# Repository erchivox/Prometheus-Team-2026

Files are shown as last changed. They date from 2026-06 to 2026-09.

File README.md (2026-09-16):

<div align="center">
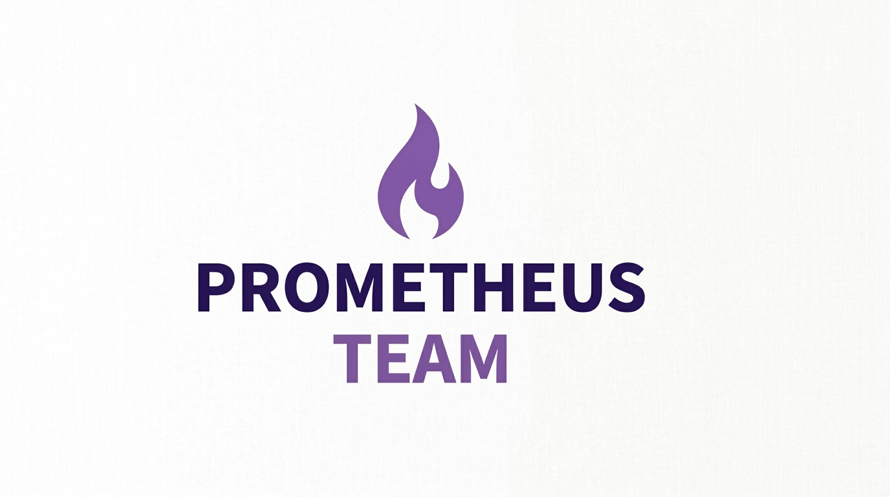
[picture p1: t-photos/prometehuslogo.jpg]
Prometheus Team Vehículo Autónomo
  

# 🚘Prometheus Team - Temporada 2026
</div>
¡Bienvenidos al repositorio oficial de nuestro equipo para la World Robot Olympiad (WRO) - Categoría: Futuros Ingenieros! Este espacio no solo almacena líneas de código, algoritmos de visión artificial y diseños en 3D; aquí se guarda la evolución, la pasión y la ingeniería de un equipo que no se rinde ante  los desafíos. Somos un equipo venezolano representando con orgullo a la **Universidad Politécnica Territorial José Félix Ribas (UPTJFR)**. Nuestro compromiso es la innovación y el aprendizaje continuo en el campo de la robótica autónoma. Queremos continuar lo que empezamos el año pasado y superar nuestros limites esta temporada.

---

## 📑 Índice

<table>
<tr><td valign="top" width="50%">

- [1. Fotos del Equipo](#1-fotos-del-equipo)
- [2. La Hazaña de 2025: Subcampeones Nacionales](#2-la-hazaña-de-2025-subcampeones-nacionales)
- [3. 2026: Con la Mira en el Primer Lugar](#3-2026-con-la-mira-en-el-primer-lugar)
- [4. Fotos del Vehículo](#4-fotos-del-vehículo)
- [5. Componentes de Control, Detección e Interfaz](#5-componentes-de-control-detección-e-interfaz)
- [6. Componentes de Alimentación y Actuación](#6-componentes-de-alimentación-y-actuación)
- [7. Esquemas de Alimentación y Cableado](#7-esquemas-de-alimentación-y-cableado)
  - [7.1. Versión 4 (Actual)](#71-versión-4-actual)
  - [7.2. Arquitectura de Energía, Control y Gestión de Potencia](#72-arquitectura-de-energía-control-y-gestión-de-potencia)
- [8. Esquemas de Sensores y Adquisición de Datos](#8-esquemas-de-sensores-y-adquisición-de-datos)
  - [8.1. Versión 4 (Actual)](#81-versión-4-actual)
  - [8.2. Optimización del Sistema de Sensores y Hardware](#82-optimización-del-sistema-de-sensores-y-hardware)
    - [8.2.1. Subsistema de Navegación Cinemática (Bus I2C 1)](#821-subsistema-de-navegación-cinemática-bus-i2c-1)
    - [8.2.2. Subsistema de Lectura de Superficie (Bus I2C 2)](#822-subsistema-de-lectura-de-superficie-bus-i2c-2)
    - [8.2.3. Subsistema de Proximidad Redundante e Interfaz](#823-subsistema-de-proximidad-redundante-e-interfaz)
  - [8.3. Resumen de Cambios y Evolución de Hardware](#83-resumen-de-cambios-y-evolución-de-hardware)
- [9. Gestión Energética y Autonomía del Sistema](#9-gestión-energética-y-autonomía-del-sistema)
  - [9.1. Cálculo del Consumo Energético Total](#91-cálculo-del-consumo-energético-total)
  - [9.2. Estimación de la Autonomía](#92-estimación-de-la-autonomía)
    - [9.2.1. Fórmula General](#921-fórmula-general)
    - [9.2.2. Aplicación al Caso de Estudio](#922-aplicación-al-caso-de-estudio)
  - [9.3. Justificación de la Fuente de Alimentación](#93-justificación-de-la-fuente-de-alimentación)
    - [9.3.1. Elección del Sistema: ¿Por qué LiPo?](#931-elección-del-sistema-por-qué-lipo)
    - [9.3.2. Análisis Comparativo de Tecnologías](#932-análisis-comparativo-de-tecnologías)
    - [9.3.3. Justificación Técnica frente a Alternativas](#933-justificación-técnica-frente-a-alternativas)

</td><td valign="top" width="50%">

- [10. Diseño Estructural, Transmisión y Manufactura Aditiva](#10-diseño-estructural-transmisión-y-manufactura-aditiva)
  - [10.1. Versión 2 (Actual)](#101-versión-2-actual)
  - [10.2. Filosofía de Rediseño y Prototipado Conceptual](#102-filosofía-de-rediseño-y-prototipado-conceptual)
    - [10.2.1. Prototipos Conceptuales Tempranos](#1021-prototipos-conceptuales-tempranos)
  - [10.3. Transición a CAD Profesional y Arquitectura Monochasis](#103-transición-a-cad-profesional-y-arquitectura-monochasis)
    - [10.3.1. Desglose Técnico del Tren Motriz](#1031-desglose-técnico-del-tren-motriz)
  - [10.4. Validación de Tolerancias y Ensamble Virtual](#104-validación-de-tolerancias-y-ensamble-virtual)
    - [10.4.1. Modelado de Componentes Clave y Sistemas de Anclaje](#1041-modelado-de-componentes-clave-y-sistemas-de-anclaje)
    - [10.4.2. Acoplamiento de Tracción: Adaptador para Ruedas Lego](#1042-acoplamiento-de-tracción-adaptador-para-ruedas-lego)
    - [10.4.3. Ensamble Virtual y Mitigación de Fallos](#1043-ensamble-virtual-y-mitigación-de-fallos)
  - [10.5. Segundo Piso, Separadores y Sistema de Visión Shark Fin](#105-segundo-piso-separadores-y-sistema-de-visión-shark-fin)
    - [10.5.1. Separadores Estructurales e Insertos Roscados](#1051-separadores-estructurales-e-insertos-roscados)
    - [10.5.2. Sistema de Sujeción del Teléfono (Mordaza Ajustable)](#1052-sistema-de-sujeción-del-teléfono-mordaza-ajustable)
  - [10.6. Integración Total: Ensamble Maestro CAD](#106-integración-total-ensamble-maestro-cad)
  - [10.7. Ingeniería de Manufactura Aditiva](#107-ingeniería-de-manufactura-aditiva)
    - [10.7.1. Optimizaciones de Impresión](#1071-optimizaciones-de-impresión)
  - [10.8. Dimensiones Finales y Resumen de Logros Estructurales](#108-dimensiones-finales-y-resumen-de-logros-estructurales)
- [11. Continuidad en el Desarrollo de Software y Control](#11-continuidad-en-el-desarrollo-de-software-y-control)
  - [11.1. Integración del BNO055](#111-integración-del-bno055)
  - [11.2. Resumen Ejecutivo de la Lógica de Control](#112-resumen-ejecutivo-de-la-lógica-de-control)
    - [11.2.1. Modo Vuelta Libre (Navegación de Pista Vacía)](#1121-modo-vuelta-libre-navegación-de-pista-vacía)
- [12. Prueba de Vueltas a la Pista](#12-prueba-de-vueltas-a-la-pista)
- [13. Archivo Histórico: Temporada 2025](#13-archivo-histórico-temporada-2025)

</td></tr>
</table>

---

## 1. Equipo Prometheus 
Prometheus Team está conformados por estudiantes universitarios de la **Universidad Politécnica Territorial "José Félix Ribas"**, destancandonos por nuestra anterior participación en la WRO 2025 y nuestro sistema de detección innovador:

### 1.1. 👤 Samuel Pérez 
**Diseñador de Entornos 3D, Desarrollador Móvil y Modelado CAD**
<div align="center">
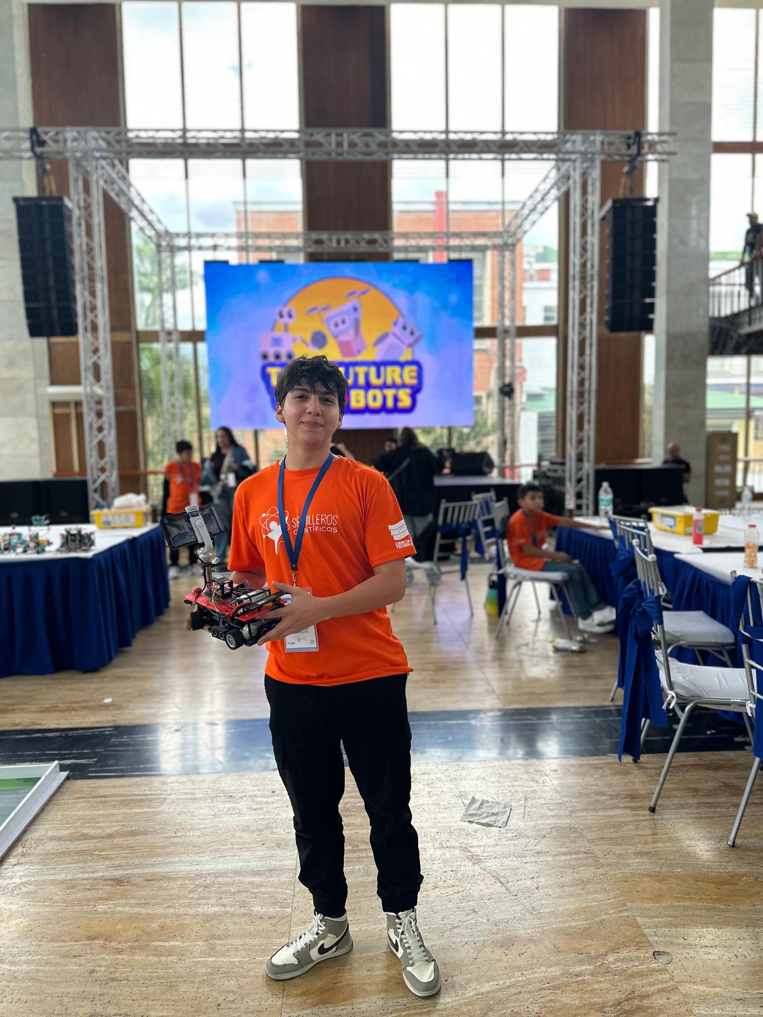
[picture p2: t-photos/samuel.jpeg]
Samuel Pérez
  
</div>

* **Trayectoria Académica:** Estudiante de Ingeniería Electrónica – **Universidad Politécnica Territorial José Félix Ribas (UPTJFR)**.
* **Competencias y Funciones Técnicas:**
  * **Diseño Estructural y Modelado 3D:** Creación paramétrica y desarrollo de componentes mecánicos optimizados para alta resistencia.
  * **Desarrollo de Software Móvil:** Creación de aplicaciones interactivas en **Android Studio** orientadas a la gestión y monitoreo de sistemas.
  * **Gestión de Proyectos:** Caracterizado por su alto nivel de responsabilidad, perseverancia y atención al detalle en entregables técnicos.
  * **Logros Destacados:** Finalista en la fase nacional de la **WRO Venezuela (Temporada 2025)** por su integración entre hardware y software.
---
### 1.2. 👤 Trino Carrizales 
**Especialista en Programación Embebida, Algoritmos y Control**
<div align="center">
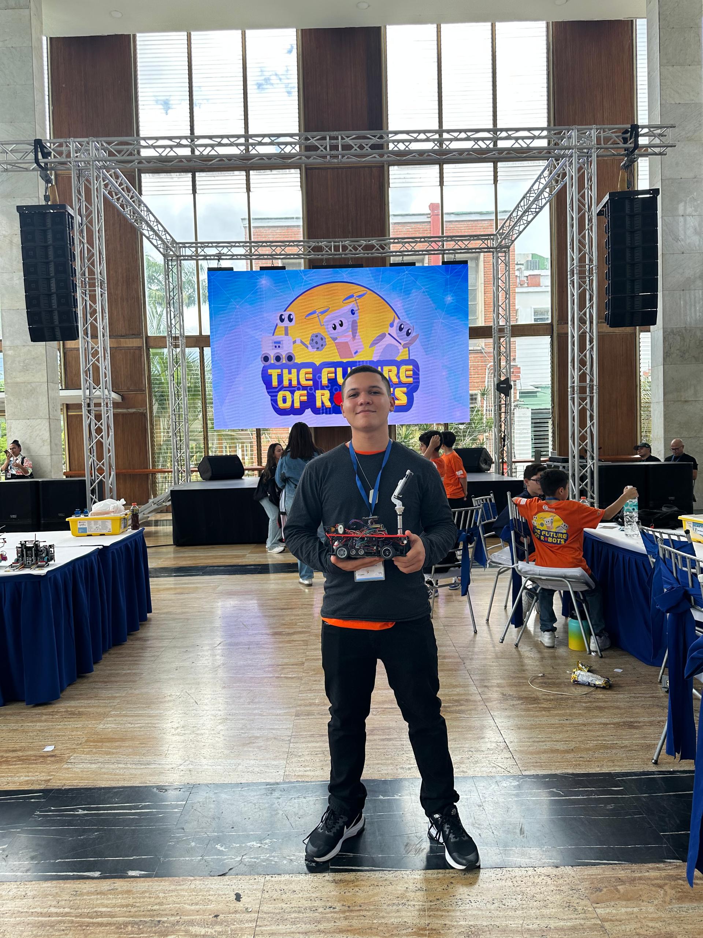
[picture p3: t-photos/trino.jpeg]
Trino Carrizales
  
</div>

* **Perfil Académico:** 
  * Estudiante de Ingeniería Electrónica – **Universidad Politécnica Territorial José Félix Ribas (UPTJFR)**.
  * Estudiante de Ingeniería en Sistemas – **Universidad Nacional Experimental de los Llanos Occidentales Ezequiel Zamora (UNELLEZ)**.
* **Dominio Técnico y Desempeño:**
  * **Desarrollo de Firmware:** Programación y optimización de código para microcontroladores **Arduino** y **ESP32**.
  * **Depuración de Software:** Diagnóstico y resolución ágil de errores lógicos e imprevistos en código fuente bajo presión.
  * **Trayectoria Competitiva:** Finalista nacional en la **WRO Venezuela (Temporada 2025)**, demostrando adaptabilidad y estabilidad en sistemas de control.
---
### 1.3. 👤 Leandro Padrón 
**Coordinador de Logística, Mecánica Aplicada y Diagnóstico Físico**
<div align="center">
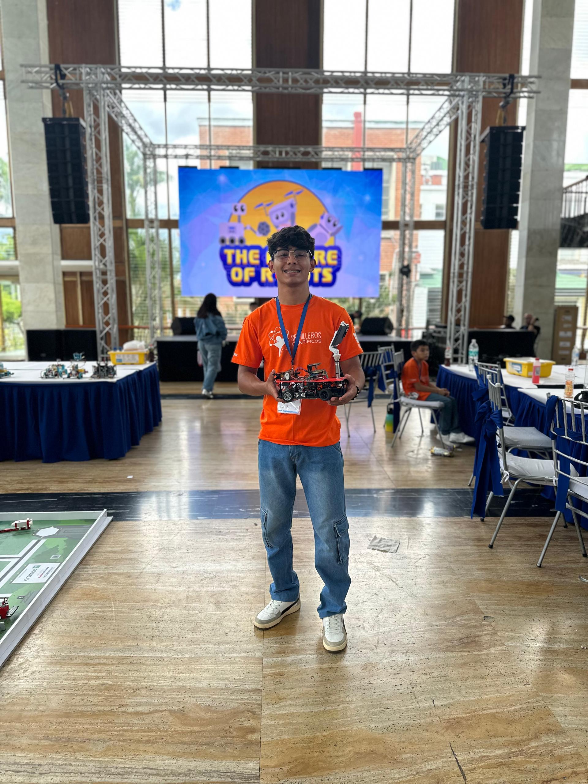
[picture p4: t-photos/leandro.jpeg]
Leandro Padrón
  
</div>

* **Estudios Universitarios:** Estudiante de Ingeniería Electrónica – **Universidad Politécnica Territorial José Félix Ribas (UPTJFR)**.
* **Aportes y Responsabilidades del Rol:**
  * **Análisis Físico-Mecánico:** Resolución eficaz de contingencias dinámicas y ensamblajes mecánicos en prototipos.
  * **Gestión Operativa:** Coordinación de recursos técnicos, planeación logística y soporte directo en las actividades de campo.
  * **Liderazgo Operativo:** Habilidad para resolver fallas de manera expedita mientras impulsa la cohesión y el trabajo en equipo.
---
### 1.4. 👤 Ing. Dayana Pérez 
**Mentora Principal y Asesora de Investigación Tecnológica**
<div align="center">
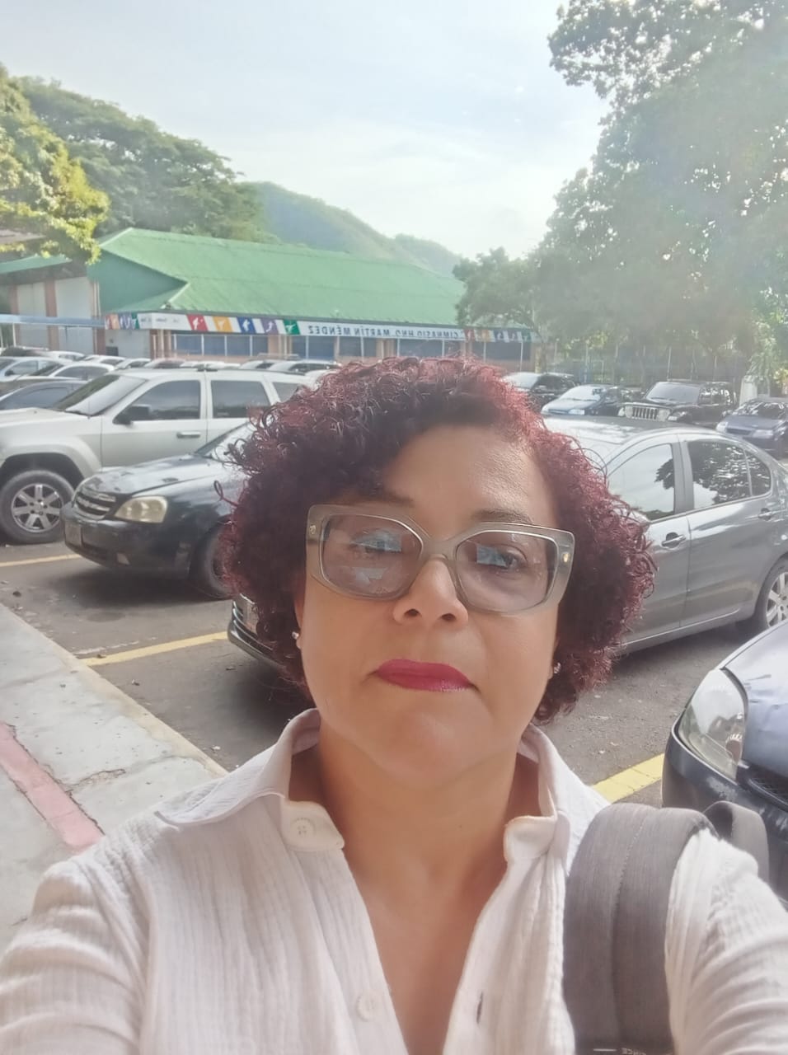
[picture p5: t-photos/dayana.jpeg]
Ing. Dayana Pérez
  
</div>

* **Acreditación y Grados Académicos:**
  * **Ingeniera Electrónica:** Universidad Politécnica Territorial Experimental Antonio José de Sucre (**UNEXPO** VR Barquisimeto).
  * **Magíster en Educación Superior:** Universidad Fermín Toro (**UFT**).
  * **Doctorante en Tecnologías de la Información y Comunicación:** Universidad Nacional Experimental de los Llanos Occidentales Ezequiel Zamora (**UNELLEZ** Barinas).
* **Orientación y Tutoría:** Asesoría metodológica en proyectos de ingeniería, supervisión académica e integración estratégica de TIC y sistemas electrónicos.

## 2. 🥈 La Hazaña de 2025: Subcampeones Nacionales

El año 2025 quedó marcado en nuestra historia. Tras meses de arduo trabajo, diseño iterativo, depuración de sensores y perfeccionamiento de la lógica de navegación autónoma, logramos alzarnos con el **2.º Lugar en la Competencia Nacional de Venezuela**.

Fue una jornada intensa donde pusimos a prueba nuestras capacidades técnicas bajo presión, enfrentándonos a los mejores equipos del país. Superamos obstáculos en la pista, calibramos componentes en tiempo récord y demostramos el nivel de la ingeniería venezolana. Estuvimos a solo un paso de la gloria máxima, y esa experiencia nos transformó por completo como desarrolladores y pensadores críticos.

## 3. 🥇 2026: Con la Mira en el Primer Lugar

Dicen que el segundo lugar es el primer perdedor, pero para nosotros fue el combustible perfecto. Este año regresamos a la pista con más experiencia, una mentalidad más madura y un hambre voraz de victoria.

Hemos analizado cada fallo del año pasado, rediseñado nuestra arquitectura de hardware y optimizado los algoritmos de control para que el robot sea más rápido, preciso e inteligente. No venimos a ver qué pasa; venimos a buscar ese **1.er Lugar nacional** y ganarnos el derecho de representar a Venezuela en el escenario mundial. La meta es clara y el equipo está listo.

---

### 3.1. 📸 Nuestro Paso por la Competencia Nacional

<p align="center">
  Foto Oficial del Equipo
  Equipo en Competencia
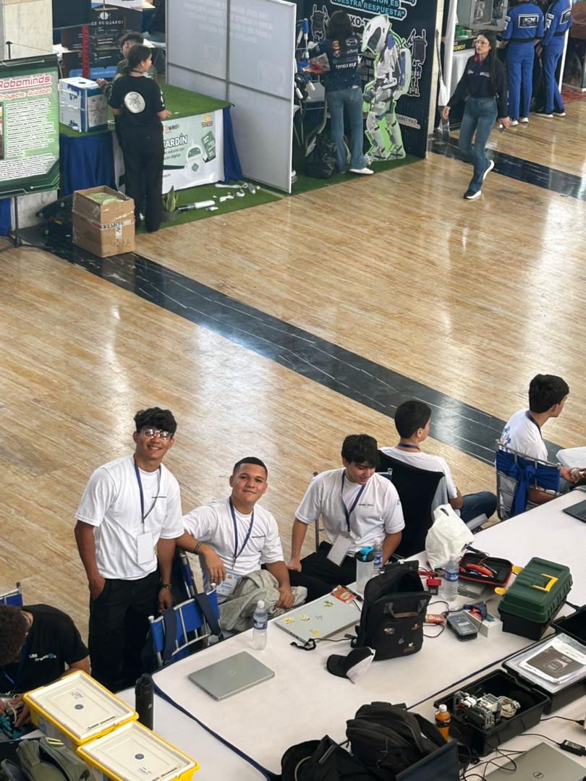
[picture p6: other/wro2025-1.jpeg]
Momento WRO 2025
  
</p>

<details>
  <summary>🔍 <b>Ver más momentos de la WRO 2025</b></summary>
  <br>
  <p align="center">
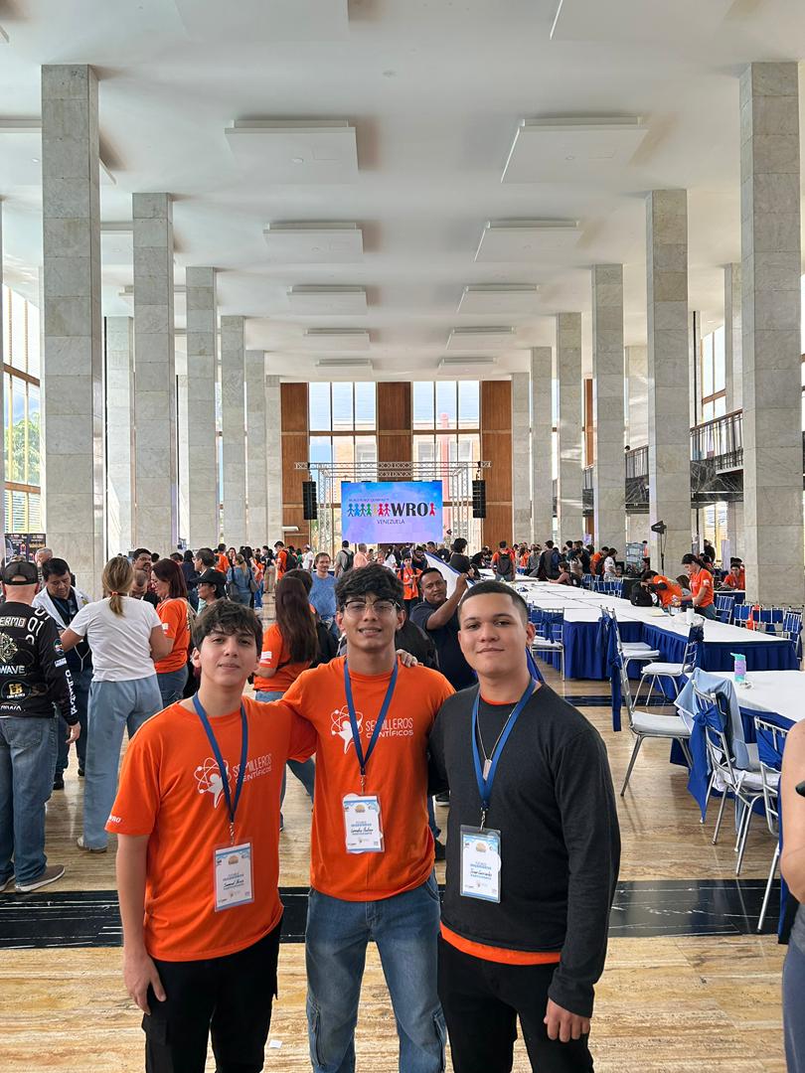
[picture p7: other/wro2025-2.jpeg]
WRO 2025 - Foto 2
    
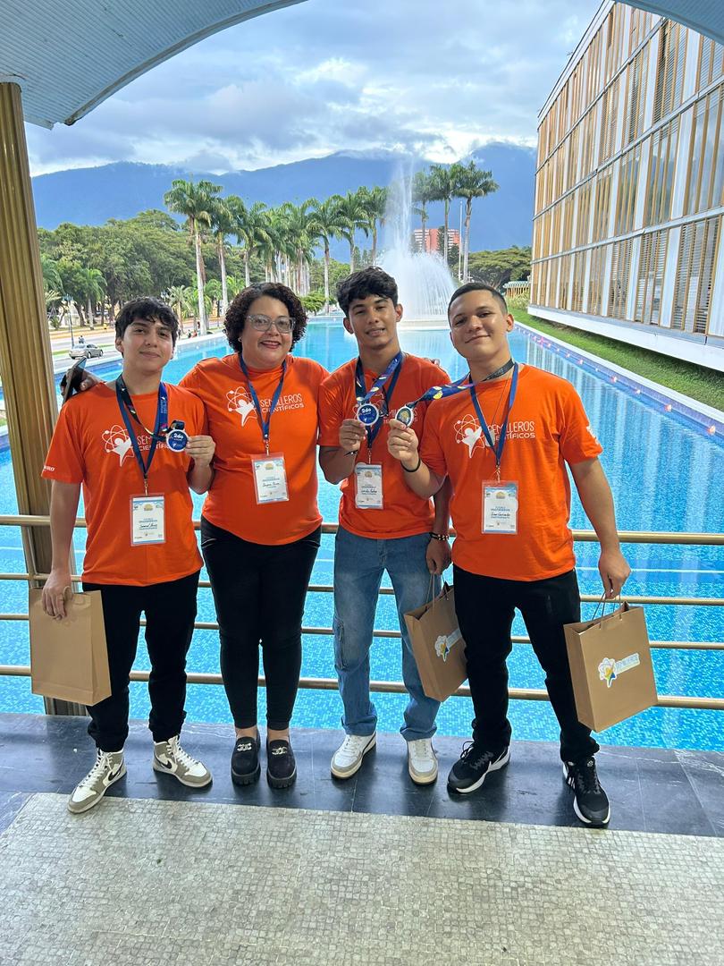
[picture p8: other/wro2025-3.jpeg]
WRO 2025 - Foto 3
    
  </p>
</details>

---

### 3.2. Galería de Inspección Técnica 360°
Para verificar la simetría estructural, la distribución del centro de masa ($CoG$), la integridad del chasis impreso en 3D y la holgura funcional (*ground clearance*), se documentan los **6 perfiles de inspección ortogonal reglamentarios**:

| 📸 Perfil de Inspección | 🖼️ Registro Visual | 🔍 Criterio de Verificación Técnica de Ingeniería |
| :--- | :--- | :--- |
| **Vista Frontal**<br>*(Front View)* | Perfil Delantero | • Verificación del sistema de visión artificial y sensores de detección frontal.<br>• Inspección de la alineación y paralelismo del mecanismo de dirección.<br>• Control del despeje inferior del parachoques y centrado estructural. |
| **Vista Trasera**<br>*(Rear View)* | Perfil Trasero | • Inspección del acople del motor de tracción y el ensamble de transmisión posterior.<br>• Verificación de la rigidez de los soportes traseros y bujes de retención de las ruedas motrices.<br>• Organización de los conectores de salida y cableado del tren de potencia. |
| **Vista Superior**<br>*(Top View)* | Perfil Superior | • Evaluación del balance transversal de pesos.<br>• Verificación del centrado de la placa lógica principal y sensores inerciales/de navegación.<br>• Ruteo, segregación y peinado del cableado de control y potencia entre niveles. |
| **Vista Inferior**<br>*(Bottom View)* | Perfil Inferior | • Inspección de la base del chasis para garantizar un acabado liso y plano sin fricciones.<br>• Verificación del despeje de suelo (*ground clearance*) para evitar contacto con desniveles.<br>• Comprobación de la fijación de la tornillería y tuercas autoblocantes empotradas. |
| **Vista Lateral Derecha**<br>*(Right View)* | Perfil Derecho | • Verificación del acceso a la interfaz física (switches de encendido / botones de control).<br>• Evidencia de la separación multinivel (pisos de tracción, lógica y potencia).<br>• Alineación y perpendicularidad de los sensores laterales derechos de medición.<br>• Inspección de la holgura lateral y alineación de las ruedas directrices y motrices. |
| **Vista Lateral Izquierda**<br>*(Left View)* | Perfil Izquierdo | • Disposición del sistema de sensores ultrasónicos / distancia del lado izquierdo.<br>• Comprobación de las rutas de ventilación pasiva y disipación térmica de los módulos de potencia. |

---

## 4. Componentes de Control, Detección e Interfaz

| Imagen | Nombre de Componente | Descripción | 🔗 Referencias y Documentación |
| :----: | :--- | :--- | :--- |
| ESP32 | **Microcontrolador ESP32** | Cerebro central del vehículo autónomo. Cuenta con un procesador de doble núcleo, conectividad Wi-Fi/Bluetooth, y múltiples pines GPIO para gestionar la lectura de sensores (I2C y Analógicos) y el control de actuadores en tiempo real. | • [Espressif ESP32 Datasheet](https://www.espressif.com/sites/default/files/documentation/esp32_datasheet_en.pdf)<br>• [Documentación ESP-IDF / Arduino ESP32](https://docs.espressif.com/projects/arduino-esp32/en/latest/) |
| Sensor Sharp | **Sensor Infrarrojo Sharp GP2Y0A21** | Sensores analógicos de medición de distancia por triangulación infrarroja. Colocados estratégicamente en el chasis para detectar obstáculos en las diagonales delanteras del vehículo y evitar colisiones de rango medio (10 a 80 cm). | • [Sharp GP2Y0A21YK0F Datasheet](https://global.sharp/products/device/lineup/data/pdf/datasheet/gp2y0a21yk_e.pdf)<br>• [Guía de Calibración Sharp IR](https://www.pololu.com/product/136) |
| Sensor TOF | **Sensores de Distancia Láser TOF VL53L0X** | Sensores basados en tecnología Time-of-Flight (Tiempo de Vuelo) que miden distancias precisas mediante luz láser invisible. Conectados en paralelo al Bus I2C #1, utilizan pines digitales individuales como selectores de dirección (XSHUT) para evitar conflictos de direccionamiento. | • [STMicroelectronics VL53L0X Datasheet](https://www.st.com/resource/en/datasheet/vl53l0x.pdf)<br>• [Librería Adafruit VL53L0X (GitHub)](https://github.com/adafruit/Adafruit_VL53L0X) |
| IMU BNO055 | **IMU BNO055 (9-Axis Absolute Orientation)** | Unidad de medición inercial avanzada que integra acelerómetro, giroscopio y magnetómetro en 3 ejes, junto con un procesador interno que calcula la orientación absoluta (ángulos de Euler/Cuaterniones) de forma directa a través del Bus I2C #1. | • [Bosch Sensortec BNO055 Datasheet](https://www.bosch-sensortec.com/media/boschsensortec/downloads/datasheets/bst-bno055-ds000.pdf)<br>• [Librería Adafruit BNO055 (GitHub)](https://github.com/adafruit/Adafruit_BNO055) |
| Sensor de Color TCS34725 | **Sensor de Color TCS34725** | Sensor de luz de color RGB con filtro infrarrojo. Conectado de forma independiente al Bus I2C #2 para evitar saturación de datos, está ubicado en la parte inferior del vehículo para identificar líneas, marcas y colores específicos en la pista. | • [AMS TCS34725 Datasheet](https://ams.com/documents/20143/36005/TCS34725_DS000390_3-00.pdf)<br>• [Librería Adafruit TCS34725 (GitHub)](https://github.com/adafruit/Adafruit_TCS34725) |
| Tira Neopixel | **Tira de LEDs Neopixel** | Sistema de iluminación e indicadores visuales RGB direccionables de forma serial a través del pin digital D14. Se utiliza para mostrar estados del software, alertas del sistema o modos de conducción de forma dinámica. | • [Worldsemi WS2812B / Neopixel Datasheet](https://cdn-shop.adafruit.com/datasheets/WS2812B.pdf)<br>• [Librería Adafruit NeoPixel (GitHub)](https://github.com/adafruit/Adafruit_NeoPixel) |
| Buzzer | **Zumbador (Buzzer)** | Transductor piezoeléctrico conectado al pin digital D4. Emite señales acústicas y alarmas sonoras para retroalimentar las diferentes etapas del programa, fallos de lectura o alertas críticas del vehículo. | • [Guía de Tono Arduino PWM / Buzzer](https://www.arduino.cc/reference/en/language/functions/advanced-io/tone/)<br>• [Especificaciones de Zumbadores Piezoeléctricos](https://www.sparkfun.com/products/7950) |
| Interruptor Programa | **Interruptor de Inicio de Programa** | Pulsador/interruptor conectado al pin digital D23 con resistencia pull-up/GND. Actúa como gatillo lógico para iniciar la marcha autónoma del software una vez el vehículo ha sido calibrado y posicionado. | • [Documentación de Entradas Digitales y Pull-Up en ESP32](https://docs.espressif.com/projects/esp-idf/en/latest/esp32/api-reference/peripherals/gpio.html) |

## 5. Componentes de Alimentación y Actuación

| Imagen | Nombre de Componente | Descripción | 🔗 Referencias y Documentación |
| :----: | :--- | :--- | :--- |
| Batería LIPO | **Batería LiPo 2S 50C 2200mAh** | Fuente de energía principal del vehículo. Suministra un voltaje nominal de 7.4V (máximo de 8.4V en carga completa) con una alta tasa de descarga (50C) para soportar los picos de corriente de los motores. | • [Especificaciones de Baterías LiPo 2S (7.4V)](https://www.hobbywing.com/) |
| Interruptor | **Interruptor de Encendido General** | Interruptor basculante (ON/OFF) conectado directamente al terminal positivo de la batería para cortar o permitir el paso de corriente a todo el sistema eléctrico de forma segura. | • [Especificaciones de Interruptores Basculantes KCD1](https://www.sparkfun.com/products/11138) |
| Step up-down XL6009 | **Regulador Elevador/Reductor XL6009** | Módulo de regulación de voltaje ajustado entre 6V y 8V (según la velocidad buscada). Estabiliza la alimentación que va dirigida al driver de los motores, independientemente de las fluctuaciones de la batería. | • [Datasheet Módulo Boost XL6009](https://www.xlsemi.com/datasheet/XL6009%20datasheet.pdf) |
| Driver TB6612FNG | **Driver de Motores TB6612FNG** | Controlador de puente en H dual de alta eficiencia. Recibe las señales lógicas de control del ESP32 (dirección y PWM) y maneja la potencia hacia los motores DC de tracción de manera mucho más eficiente que el clásico L298N. | • [Toshiba TB6612FNG Datasheet](https://www.sparkfun.com/datasheets/Robotics/TB6612FNG.pdf) |
| Motor 25GA-370 | **Motor DC 25GA-370 (6V-8V)** | Motorreductor metálico encargado de la tracción mecánica del vehículo autónomo. Funciona en un rango de voltaje de 6V a 8V regulado por el XL6009 y operado a través del driver. | • [Especificaciones Técnicas Motorreductor 25GA-370](https://www.pololu.com/category/60/micro-metal-gearmotors) |
| Step down DSN-Mini 360 | **Step Down DSN-Mini 360** | Regulador reductor de voltaje de tipo conmutado, ajustado a una salida fija de 7V para alimentar de forma estable el pin VIN del microcontrolador ESP32. | • [MP2307 / Mini360 Step-Down Datasheet](https://www.monolithicpower.com/en/documentview/productdocument/index/doc_url/M/P/MP2307_r1.9.pdf) |
| Servomotor MG90 | **Servomotor MG90 180°** | Servo con piñonería metálica de alta resistencia. Utilizado para controlar el ángulo de dirección de las ruedas delanteras del vehículo mediante señales PWM del microcontrolador. Alimentado a 6V desde el regulador correspondiente. | • [TowerPro MG90S Micro Servo Datasheet](https://www.electronicoscaldas.com/datasheet/MG90S_Tower-Pro.pdf) |

## 6. Esquemas de Alimentación y Cableado

[*Consultar el historial de versiones de alimentación aquí*](#sistema-de-alimentación)

### 6.1. Versión 4 (Actual)

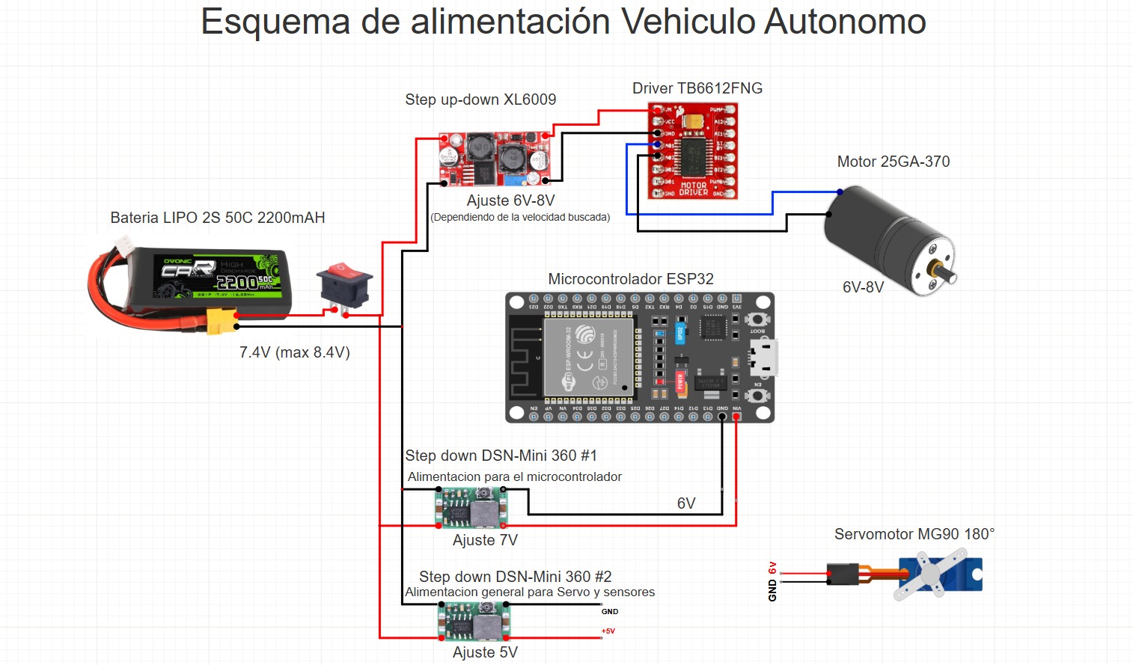
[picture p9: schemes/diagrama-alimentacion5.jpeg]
Diagrama de Alimentación V4


```mermaid
graph TD
    classDef bat fill:#d50000,stroke:#ff5252,stroke-width:2px,color:#fff;
    classDef sw fill:#424242,stroke:#bdbdbd,stroke-width:2px,color:#fff;
    classDef reg fill:#f57c00,stroke:#ffb74d,stroke-width:2px,color:#fff;
    classDef load fill:#1565c0,stroke:#64b5f6,stroke-width:2px,color:#fff;

    BAT["🔋 Bateria LiPo 2S<br>50C 2200mAh (7.4V - Max 8.4V)"]:::bat
    SW["🔘 Interruptor Encendido General"]:::sw

    XL["🚀 Step Up-Down XL6009<br>Ajuste: 6V a 8V (Motores)"]:::reg
    SD1["📉 Step Down DSN-Mini 360 1<br>Ajuste: 7V (ESP32 VIN)"]:::reg
    SD2["📉 Step Down DSN-Mini 360 2<br>Ajuste: 5V - 6V (Servo y Sensores)"]:::reg

    ESP32["🧠 Microcontrolador ESP32<br>Alimentado por VIN a 7V"]:::load
    DRIVER["🏎️ Driver TB6612FNG<br>Alimentacion VCC/VM 6V-8V"]:::load
    MOTOR["⚙️ Motor DC 25GA-370<br>Tension Variable 6V-8V"]:::load
    SERVO["📐 Servomotor MG90 180<br>Alimentado a 6V"]:::load

    BAT --> SW

    SW --> XL
    SW --> SD1
    SW --> SD2

    XL --> DRIVER
    DRIVER --> MOTOR

    SD1 --> ESP32
    SD2 --> SERVO
```
### 6.2. Arquitectura de Energía, Control y Gestión de Potencia

La **batería LiPo 2S de 2200mAh** (7.4V nominales, 8.4V en máxima carga) constituye la fuente central de energía del sistema, gestionada mediante un **interruptor general físico de palanca** que garantiza un enclavamiento mecánico seguro y mitiga fallos por desconexión accidental ante vibraciones en la pista. 

A partir de este nodo central, la alimentación se ramifica de forma completamente independiente en tres sub-buses regulados para aislar el ruido electromagnético y evitar caídas de tensión (*brownouts*) en la lógica de control:

* **Línea de Tracción Potenciada:** Una rama se dirige a un regulador **step-up/down XL6009**, ajustado dinámicamente entre 6V y 8V en función de la velocidad requerida. Este módulo alimenta el **puente H TB6612FNG**, el cual entrega el voltaje íntegro al **Motor 25GA-370**.
* **Línea de Control Confiable:** De forma paralela, un módulo **step-down DSN-Mini 360** configurado a 6V proporciona energía limpia al pin Vin del único **ESP32** del sistema, garantizando el diferencial necesario para el correcto funcionamiento de su regulador interno LDO sin riesgo de reinicios.
* **Línea de Actuadores y Sensores:** Un segundo módulo **DSN-Mini 360**, calibrado estrictamente a 5V, se encarga de la alimentación general para el **Servomotor SG90 180°** y el resto de la red de sensores, ofreciendo una línea de voltaje estable y adecuada para las comunicaciones de datos.

> [!IMPORTANT]
> **Iteración Crítica de Hardware (L298N vs. TB6612FNG)**
> 
> La transición al puente H TB6612FNG resolvió dos fallos arquitectónicos graves de nuestro prototipo inicial. En primer lugar, eliminó la severa caída de voltaje interna característica del L298N, optimizando la eficiencia del par motor. En segundo lugar, el módulo L298N generaba una interferencia que inhabilitaba los puertos I2C de cualquier microcontrolador conectado. Este fallo nos había obligado temporalmente a utilizar una arquitectura ineficiente con dos placas ESP32 (una dedicada exclusivamente al control del motor). El cambio al TB6612FNG solucionó este conflicto de comunicaciones, permitiéndonos unificar todo el procesamiento en un único ESP32. Esto redujo drásticamente el peso, la complejidad del cableado, el consumo general de energía y los posibles puntos de fallo del vehículo.

> [!NOTE]
> **Compensación de diseño (*Trade-off*)**
> 
> Esta configuración ampliada, apoyada en tres reguladores de voltaje independientes, exige una gestión del espacio interno más rigurosa dentro del chasis impreso en 3D. Sin embargo, se asumió esta compensación espacial porque mitiga por completo el acoplamiento de ruido inductivo provocado por los motores hacia la electrónica sensible, blindando la estabilidad del vehículo y asegurando lecturas limpias en el bus I2C durante la navegación autónoma.

## 7. Esquemas de Sensores y Adquisición de Datos

[*Consultar el historial de versiones de detección aquí*](#sistema-de-detección-de-objetos)

### 7.1. Versión 4 (Actual)

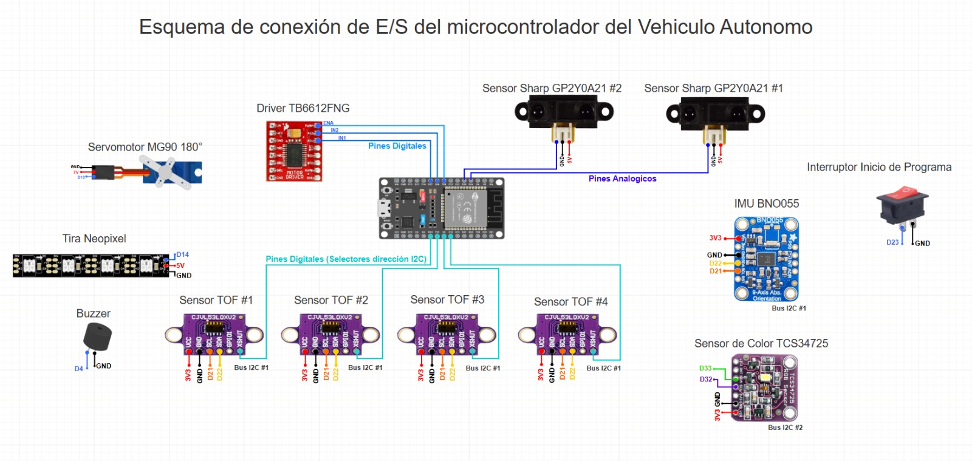
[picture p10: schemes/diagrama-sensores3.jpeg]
Diagrama de Sensores V4


```mermaid
graph TD
    classDef mcu fill:#2b2b2b,stroke:#00e676,stroke-width:2px,color:#fff;
    classDef i2c1 fill:#1a237e,stroke:#448aff,stroke-width:2px,color:#fff;
    classDef i2c2 fill:#4a148c,stroke:#e040fb,stroke-width:2px,color:#fff;
    classDef adc fill:#e65100,stroke:#ff9100,stroke-width:2px,color:#fff;
    classDef gpio fill:#004d40,stroke:#00bfa5,stroke-width:2px,color:#fff;

    MCU["⚡ ESP32 Mainboard"]:::mcu

    IMU["🧭 IMU BNO055"]:::i2c1
    TOF1["🎯 Sensor TOF 1 VL53L0X"]:::i2c1
    TOF2["🎯 Sensor TOF 2 VL53L0X"]:::i2c1
    TOF3["🎯 Sensor TOF 3 VL53L0X"]:::i2c1
    TOF4["🎯 Sensor TOF 4 VL53L0X"]:::i2c1

    COLOR["🎨 Sensor Color TCS34725"]:::i2c2

    SHARP1["📡 Sensor Sharp 1 GP2Y0A21"]:::adc
    SHARP2["📡 Sensor Sharp 2 GP2Y0A21"]:::adc

    SERVO["⚙️ Servomotor MG90 Pin D13"]:::gpio
    NEO["🌈 Tira Neopixel RGB Pin D14"]:::gpio
    BUZZER["🔔 Buzzer Piezoelectrico Pin D4"]:::gpio
    SW["🔘 Switch Inicio Programa Pin D23"]:::gpio
    DRIVER["🏎️ Driver TB6612FNG Control Motores"]:::gpio
    XSHUT["🔀 Selectores XSHUT Control TOF"]:::gpio

    MCU --> IMU
    MCU --> COLOR

    MCU --> XSHUT
    XSHUT --> TOF1
    XSHUT --> TOF2
    XSHUT --> TOF3
    XSHUT --> TOF4

    SHARP1 --> MCU
    SHARP2 --> MCU

    MCU --> SERVO
    MCU --> NEO
    MCU --> BUZZER
    SW --> MCU
    MCU --> DRIVER
```
### 7.2. Optimización del Sistema de Sensores y Hardware

En esta cuarta iteración, se ha reconfigurado la matriz de sensores del vehículo aprovechando la capacidad de múltiples buses del ESP32. El objetivo principal es maximizar la precisión espacial, evitar cuellos de botella en el procesamiento de datos y blindar la estabilidad del algoritmo de navegación autónoma dentro de la pista de $3 \times 3$ metros.

#### 7.2.1. Subsistema de Navegación Cinemática (Bus I2C 1)

* **Sensores de Distancia por Tiempo de Vuelo (ToF):** El reemplazo de los transductores ultrasónicos por módulos ToF elimina las zonas muertas en lecturas de corto alcance. Para conectar los cuatro sensores en el mismo bus I2C, se implementó una estrategia de asignación de direcciones dinámicas controlando los pines **XSHUT** a través de pines digitales del ESP32, lo que permite un encendido secuencial. Además, al operar nativamente a 3.3V, esta actualización eliminó la necesidad de utilizar divisores de tensión, simplificando drásticamente el hardware.
* **Unidad de Medición Inercial (IMU) BNO055:** Comparte el Bus I2C #1. La inclusión de este sensor con procesamiento de fusión de datos a bordo está orientada a **eliminar por completo la deriva (*drift*)** acumulativa. Para garantizar la fidelidad del posicionamiento, el algoritmo calibra el cero relativo y establece el eje Y del sensor como el vector de referencia principal para el equilibrio y dirección del chasis.

#### Subsistema de Navegación Cinemática (Bus I2C #1 - Pines D21/D22)

* **Unidad de Medición Inercial (IMU) BNO055:** Comparte el Bus I2C #1. La inclusión de este sensor con procesamiento de fusión de datos a bordo está orientada a **eliminar por completo la deriva (*drift*)** acumulativa. Para garantizar la fidelidad del posicionamiento, el algoritmo calibra el cero relativo y establece el eje Y del sensor como el vector de referencia principal para el equilibrio y dirección del chasis.

* **Sensores de Distancia por Tiempo de Vuelo (ToF):** El reemplazo de los transductores ultrasónicos por módulos ToF elimina las zonas muertas en lecturas de corto alcance. Para conectar los cuatro sensores en el mismo bus I2C, se implementó una estrategia de asignación de direcciones dinámicas controlando los pines **XSHUT** a través de pines digitales del ESP32, lo que permite un encendido secuencial. Además, al operar nativamente a 3.3V, esta actualización eliminó la necesidad de utilizar divisores de tensión, simplificando drásticamente el hardware.

#### 7.2.2. Calibración y Direccionamiento de los 4 Sensores ToF (XSHUT)

Los cuatro sensores VL53L0X comparten el mismo bus físico I2C #1 (pines D21/D22), pero de fábrica todos responden a la misma dirección por defecto (`0x29`), lo que provocaría colisión de direcciones si se energizaran simultáneamente. Para resolverlo, cada sensor tiene su pin **XSHUT** conectado a un GPIO independiente del ESP32, usado como interruptor de encendido/apagado por software:

```cpp
#define XSHUT_FRONTAL 17
#define XSHUT_TRASERO 16
#define XSHUT_IZQ     5
#define XSHUT_DER     18

#define ADDR_FRONTAL 0x30
#define ADDR_TRASERO 0x31
#define ADDR_IZQ     0x32
#define ADDR_DER     0x33
```

**Secuencia de inicialización (encendido escalonado):**

```mermaid
flowchart TD
    A["Inicio: los 4 pines XSHUT en LOW<br/>(los 4 sensores en reset/apagado)"] --> B["Activar XSHUT_FRONTAL (HIGH)"]
    B --> C["Inicializar sensor en dirección<br/>de fábrica 0x29"]
    C --> D["Reasignar dirección → 0x30<br/>(ADDR_FRONTAL)"]
    D --> E["Activar XSHUT_TRASERO (HIGH)"]
    E --> F["Inicializar en 0x29 → reasignar a 0x31"]
    F --> G["Activar XSHUT_IZQ (HIGH)"]
    G --> H["Inicializar en 0x29 → reasignar a 0x32"]
    H --> I["Activar XSHUT_DER (HIGH)"]
    I --> J["Inicializar en 0x29 → reasignar a 0x33"]
    J --> K["Los 4 sensores activos,<br/>cada uno con dirección única<br/>en el mismo bus I2C #1"]
```

En cada paso, solo **un sensor a la vez** queda activo en la dirección por defecto `0x29` mientras los demás permanecen en reset (XSHUT en LOW), evitando cualquier colisión. Una vez reasignada su dirección definitiva, el sensor permanece encendido (XSHUT en HIGH) y se pasa al siguiente.

> [!NOTE]
> **Calibración: los 4 sensores usan el mismo criterio (sin offsets individuales)**
>
> Los cuatro VL53L0X se calibran de forma idéntica, sin aplicar offsets particulares por unidad. Esto es posible porque el VL53L0X trae calibración de fábrica consistente entre unidades del mismo lote, y el direccionamiento único vía XSHUT es lo único que realmente necesita configurarse por sensor — no la calibración de medición en sí.

#### 7.2.3. Subsistema de Lectura de Superficie (Bus I2C 2)

* **Sensor de Color TCS34725:** Dedicado a la detección y confirmación de líneas. Para evitar saturar el bus principal de navegación, este sensor se ha aislado en un **segundo bus I2C independiente (Hardware I2C #2)**. Esto garantiza que las lecturas constantes del suelo no interfieran ni retrasen las respuestas críticas de evasión de obstáculos de los sensores ToF.

#### 7.2.4. Subsistema de Proximidad Redundante e Interfaz

* **Sensores Sharp GP2Y0A21 Diagonales:** Mantienen su conexión analógica tradicional para ofrecer detección de proximidad redundante en los ángulos ciegos frontales.
* **Interfaz de Usuario y Control:** Se integró una tira Neopixel y un Buzzer para proporcionar telemetría visual y auditiva del estado del robot (códigos de error, calibración exitosa, detección de línea). El inicio de ejecución se controla mediante un **interruptor físico de palanca** (Pin D23), descartando el uso de pulsadores para evitar rebotes o activaciones accidentales por vibración.

---

> [!IMPORTANT]
> **Iteración de Hardware: Simplificación y Mantenibilidad**
> 
> La transición de los sensores ultrasónicos (HC-SR04) a los módulos ToF no solo mejoró la velocidad de muestreo, sino que resolvió un problema crítico de diseño físico. En versiones anteriores, la incompatibilidad lógica (5V del HC-SR04 vs. 3.3V de los pines del ESP32) nos obligó a fabricar divisores de voltaje manuales con arreglos de resistencias debido a la falta de convertidores lógicos comerciales en ese momento. Aunque la solución era funcional, resultaba en un circuito sumamente tosco, voluminoso y propenso a falsos contactos. Migrar a una topología de sensores I2C nativos a 3.3V eliminó por completo esta red pasiva, logrando un ensamblaje mucho más limpio y facilitando enormemente las labores de mantenimiento y reparación en los pits durante la competencia.

> [!NOTE]
> **Compensación de Diseño (*Trade-off*) y Gestión de Tráfico I2C**
> 
> Integrar múltiples sensores I2C presentaba el riesgo de colisiones de datos y retrasos en el ciclo principal (*loop*). Este riesgo se mitigó mediante dos decisiones arquitectónicas: a nivel de software, implementando rutinas de muestreo secuencial (*polling*) estrictamente temporizadas mediante los pines XSHUT; y a nivel de hardware, segregando la carga de datos en dos buses I2C independientes (Navegación vs. Superficie). Adicionalmente, para optimizar el espacio y peso, se decidió prescindir de bancos de resistencias *pull-up* externas, confiando exitosamente en las resistencias *pull-up* integradas por defecto en las placas comerciales de los sensores.

---

### 7.3. Resumen de Cambios y Evolución de Hardware

| Componente Anterior | Componente Actual | Justificación Técnica y Ventaja Principal |
| :--- | :--- | :--- |
| Sensor Ultrasónico (HC-SR04 con divisores de tensión) | **4x Sensores ToF (I2C #1)** | Eliminación de zonas muertas y de redes de resistencias; hardware limpio a 3.3V. Direcciones gestionadas vía pines XSHUT. |
| Giroscopio básico | **IMU BNO055 (I2C #1)** | Supresión del *drift* inercial en el área de $3 \times 3$ m (Alineación orientada al eje Y). |
| Sensor de Color (Bus único) | **TCS34725 (I2C #2 aislado)** | Independencia de bus para evitar cuellos de botella con la telemetría de evasión. |
| Pulsador de inicio | **Interruptor físico (Pin D23)** | Enclavamiento seguro contra vibraciones mecánicas de la pista. |

---

## 8. Gestión Energética y Autonomía del Sistema

Este apartado detalla el análisis del consumo eléctrico y la justificación técnica de la fuente de alimentación seleccionada para el hardware del proyecto.

### 8.1. Cálculo del Consumo Energético Total

El consumo eléctrico del sistema se estimó para tres escenarios de operación por componente, siguiendo valores típicos de hoja de datos: **standby** (componente energizado pero inactivo o en reposo), **nominal** (operación típica durante una vuelta normal) y **pico** (consumo máximo instantáneo, por ejemplo arranque de motor o brillo máximo de LEDs).

| Componente | Cantidad | Standby (mA) | Nominal (mA) | Pico (mA) |
| :--- | :---: | :---: | :---: | :---: |
| **ESP32** (doble núcleo, WiFi/BT off) | 1 | ~20 mA (idle) | ~80 mA | ~80 mA (procesamiento intensivo) |
| **Sensor Infrarrojo Sharp GP2Y0A21** | 2 | 10 mA c/u | 30 mA c/u | 33 mA c/u |
| **Sensor ToF VL53L0X** | 4 | 5 mA c/u | 15 mA c/u | 20 mA c/u (ranging activo) |
| **IMU BNO055** | 1 | ~1 mA | 12.3 mA | ~16 mA |
| **Sensor de Color TCS34725** | 1 | ~0 mA (sleep, µA) | 3 mA | 3.6 mA |
| **Tira Neopixel** (10 LEDs) | 10 | 0 mA (apagada) | 300 mA (mix medio) | 600 mA (blanco 100%) |
| **Zumbador (Buzzer)** | 1 | 0 mA | 30 mA | 30 mA |
| **Regulador XL6009** | 1 | 15 mA (quiescent) | 15 mA | 15 mA |
| **Driver TB6612FNG** (lógica) | 1 | 1 mA | 2 mA | 6 mA |
| **Motor DC 25GA-370** | 1 | 0 mA (detenido) | 500 mA | ~1800 mA (corriente de rotor bloqueado / arranque) |
| **Step Down DSN-Mini 360** | 2 | 5 mA c/u | 5 mA c/u | 5 mA c/u |
| **Servomotor MG90** | 1 | 10 mA (sosteniendo posición) | 200 mA (en movimiento) | ~700 mA (esfuerzo/stall) |
| **TOTAL ESTIMADO** | | **~97 mA** | **~1272.3 mA** | **~3406.6 mA** |

🔋 **Demanda de Corriente Nominal:** ~1.27 A · **Pico teórico simultáneo:** ~3.41 A

> [!NOTE]
> **Sobre el escenario de pico**
>
> El pico de ~3.41 A representa el caso extremo en que *todos* los componentes alcanzan su consumo máximo al mismo tiempo (arranque del motor + servo en esfuerzo + LEDs en blanco pleno). Es un escenario estadísticamente improbable en un ciclo de control real, pero es el valor de referencia usado para dimensionar la tasa de descarga (C) mínima requerida de la batería — ver sección de justificación de la LiPo 2S 50C.

---

### 8.2. Estimación de la Autonomía

Para calcular el tiempo estimado de funcionamiento continuo, se utiliza la relación entre la capacidad nominal de la batería y la demanda de corriente calculada.

#### 8.2.1. Fórmula General
$$\text{Autonomía (horas)} = \frac{\text{Capacidad de la Batería (mAh)}}{\text{Consumo Total del Sistema (mA)}}$$

#### 8.2.2. Aplicación al Caso de Estudio
$$\text{Autonomía} \approx \frac{2200 \text{ mAh}}{1272.3 \text{ mA}} \approx 1.73 \text{ horas}$$

* **Tiempo estimado:** Aproximadamente **1 hora y 44 minutos** de operación continua en condiciones normales.
* **Nota Práctica:** Este modelo es de naturaleza teórica. En un entorno dinámico, los motores variarán su consumo constantemente (aumentando cerca del punto de bloqueo o *stall*) y los sensores se activarán por ráfagas, haciendo que la autonomía real oscile en función de las rutinas algorítmicas del firmware.

---

### 8.3. Eficiencia de los Conversores DC-DC y Autonomía Real

El cálculo de autonomía anterior asume una relación 1:1 entre la corriente consumida por cada componente y la corriente extraída de la batería, sin considerar que los reguladores XL6009 y DSN-Mini 360 operan a voltajes de salida distintos al de la batería (7V, 6V y 5V vs. 7.4V nominal) y que ninguna conversión es 100% eficiente.

**Eficiencias de referencia (según hoja de datos del fabricante):**

| Convertidor | Rol en el sistema | Eficiencia típica | Rango según fabricante |
| :--- | :--- | :---: | :---: |
| **XL6009** (step-up/down) | Línea de Tracción (motor + TB6612FNG) | ~88% | Hasta 94% en condiciones ideales; en nuestra aplicación (relación de conversión cercana a 1:1, ~500 mA de carga) el valor real práctico es menor |
| **DSN-Mini 360** ×2 (step-down, MP2307) | Línea de Control (ESP32) y Línea de Sensores/Actuadores | ~90% | 90–96% típico a carga moderada según el fabricante |

**Recálculo de la corriente real extraída de la batería (balance de potencia por línea):**

$$P_{\text{entrada}} = \frac{P_{\text{salida}}}{\eta} \qquad I_{\text{batería}} = \frac{P_{\text{entrada}}}{V_{\text{batería}}}$$

| Línea de alimentación | V salida | I salida (nominal) | P salida | η | P entrada | I extraída de batería (7.4V) |
| :--- | :---: | :---: | :---: | :---: | :---: | :---: |
| Tracción (XL6009 → Motor + TB6612) | 7 V | 502 mA | 3.51 W | 88% | 3.99 W | **≈ 540 mA** |
| Control (Mini 360 → ESP32) | 6 V | 80 mA | 0.48 W | 90% | 0.53 W | **≈ 72 mA** |
| Sensores/Actuadores (Mini 360 → Sharp+ToF+BNO+TCS+Neopixel+Buzzer+Servo) | 5 V | 665.3 mA | 3.33 W | 90% | 3.70 W | **≈ 500 mA** |
| **TOTAL REAL EXTRAÍDO DE LA BATERÍA** | | | | | | **≈ 1112 mA** |

$$\text{Autonomía real} \approx \frac{2200 \text{ mAh}}{1112 \text{ mA}} \approx 1.98 \text{ horas} \; (\approx 1\text{h}\,59\text{min})$$

> [!IMPORTANT]
> **Por qué la autonomía real es mayor que la estimación teórica inicial, no menor**
>
> A primera vista se esperaría que las pérdidas por eficiencia *reduzcan* la autonomía, y en efecto lo hacen frente al caso ideal (100% eficiencia). Pero el modelo original (~1.73 h) tenía un sesgo en sentido contrario: sumaba directamente los mA de cada componente como si todos operaran al voltaje de la batería (7.4V), cuando en realidad la mayoría opera a 5V o 6V. Al bajar el voltaje, la corriente equivalente en el lado de la batería es menor — y esa reducción por conversión de voltaje pesa más que la pérdida introducida por la eficiencia de los reguladores. El resultado neto es una autonomía real estimada (~1h 59min) **mayor** a la calculada originalmente sin este ajuste, lo cual es consistente con la observación empírica: en pruebas de una tarde y noche completas no se llegó al límite inferior de carga de la batería.

---

### 8.4. Justificación de la Fuente de Alimentación
### 🔋 Elección del Sistema de Alimentación: ¿Por qué LiPo?

La elección de una batería de **Polímero de Litio (LiPo)** frente a otras tecnologías del mercado se debe principalmente a su excelente **relación peso-potencia** y a su **capacidad de entrega de corriente instantánea (tasa de descarga)**, factores críticos para el rendimiento dinámico del robot.

---

#### 8.4.2. 📊 Análisis Comparativo de Tecnologías

| Tecnología | Densidad Energética | Tasa de Descarga (C) | Peso / Volumen | Comportamiento con Motores/Servos |
| :--- | :---: | :---: | :---: | :--- |
| **LiPo (2S 50C)** | **Alta** | **Muy Alta (~50C)** | **Muy Ligero** | **Excelente.** Entrega corriente instantánea sin caídas de voltaje. |
| **Li-ion (18650)** | Muy Alta | Baja (1C - 2C) | Ligero | **Deficiente.** Los picos de corriente provocan *voltage sag* y reinician la ESP32. |
| **NiMH (6 celdas)**| Media | Media | Muy Pesado | **Aceptable, pero inviable.** El exceso de peso penaliza la agilidad del robot. |
| **Power Bank (USB)**| Alta | Limitada (2A-3A) | Medio | **Incompatible.** Los circuitos de protección se apagan por sobrecorriente. |

---

#### 8.4.3. Justificación Técnica frente a Alternativas

##### a) Frente a Li-ion (18650)
Aunque las celdas 18650 tienen una excelente densidad energética, su tasa de descarga típica es muy baja. Si se intentan alimentar motores DC y servomotores —que generan altos picos de corriente al arrancar o atascarse— una batería Li-ion común sufrirá una caída de voltaje severa (*voltage sag*). Esto provocaría el **reinicio constante de la ESP32** o la activación del circuito de protección (BMS). La LiPo con su alta tasa de descarga entrega esa corriente al instante sin caídas de tensión.

##### b) Frente a NiMH
Las NiMH son seguras y duraderas, pero extremadamente pesadas y voluminosas. Para igualar los **7.4V** nominales de una LiPo 2S, se requerirían **6 celdas de NiMH en serie** (1.2V c/u). Este incremento de peso duplicaría o triplicaría la masa del robot, penalizando el consumo eléctrico de los motores y reduciendo drásticamente la agilidad y aceleración del sistema en pista.

##### c) Frente a Power Banks Comerciales
Los Power Banks elevan internamente el voltaje de sus celdas a 5V mediante reguladores con un límite estricto de corriente (usualmente 2A o 3A máximo). El consumo concurrente del sistema satura este límite con facilidad:
* **10 LEDs Neopixel** en blanco brillante: `~600 mA`
* **Servomotor MG90** (esfuerzo de torsión): `~500 mA`
* **Motor principal 25GA-370** (arranque/carga): `> 1A`

Superar este límite provoca un apagado inmediato del Power Bank por sobrecorriente. Además, los motores **25GA-370** rinden de manera óptima entre **6V y 8V**; alimentarlos a 5V limitaría severamente su torque y velocidad final.

#### 8.4.4. ¿Por qué 2200 mAh y no más capacidad?

La elección de la capacidad específica de 2200 mAh (y no una mayor) respondió a tres criterios evaluados en conjunto: peso, espacio y margen de autonomía real ya validado.

- **Peso:** la LiPo 2S 2200mAh 50C seleccionada pesa **115 g**. Una celda de 2600 o 3000 mAh de la misma tecnología y tasa de descarga añade masa adicional proporcional a la capacidad extra — peso que impacta directamente la relación torque/masa calculada en la sección de tracción, sin ofrecer una ventaja competitiva relevante dado que la autonomía ya cubre con holgura la duración de una prueba de competencia.
- **Tasa de descarga (50C):** con 2200 mAh y 50C, la batería puede entregar hasta 110 A de corriente instantánea — muy por encima de cualquier pico real del sistema (~3.6 A, ver tabla de consumo). Esto garantiza arranque del motor sin caídas de tensión (*voltage sag*) ni fluctuaciones que afecten a la lógica de control, sin necesitar más capacidad para lograrlo.
- **Autonomía suficiente y validada empíricamente:** según el recálculo con pérdidas de conversión (sección anterior), la autonomía real estimada es de ~1h 59min. En la práctica, el equipo utilizó el vehículo durante una tarde y noche completas de pruebas sin llegar al límite inferior de carga, confirmando que 2200 mAh ofrece margen de sobra para entrenamiento y competencia sin necesidad de cargar más peso muerto en el chasis.

> [!NOTE]
> **Compensación de Diseño (*Trade-off*)**
>
> Subir a 2600–3000 mAh habría añadido entre 20–35 g adicionales aproximadamente (estimado proporcional a la línea de productos de la misma marca/tecnología) a cambio de una autonomía que ya no es el factor limitante del sistema — el "cuello de botella" real está en el tiempo de procesamiento del algoritmo de evasión (ver comparación de tiempos de vuelta), no en la energía disponible. Se priorizó mantener el chasis lo más liviano posible.

> ⚠️ **Nota de Diseño:** La combinación de una LiPo 2S junto a una tasa de descarga de hasta 50C garantiza que la electrónica de control (ESP32) y la etapa de potencia (motores/servos) coexistan de manera estable sin interferencias por caídas de tensión.
---

## Diseño Estructural, Transmisión y Manufactura Aditiva

[*Consultar el historial de versiones de diseño estructural, transmisión y manufactura aditiva aquí*](#paso-a-paso-de-la-construcción)

### Versión 2 (Actual)

---

### 1. Filosofía de Rediseño y Prototipado Conceptual

El punto de partida de esta iteración consistió en un riguroso análisis de fallos del desempeño en los desafíos anteriores. El diagnóstico principal determinó que el chasis heredado poseía una longitud excesiva, lo que degradaba la cinemática de giro del robot y aumentaba su radio de giro, restando agilidad en las evasiones. 

Para mitigar este problema sin comprometer el espacio de la electrónica, se fijó un objetivo de diseño geométrico estricto: lograr una **relación de aspecto 1:1**. Esto significa igualar la distancia entre el eje delantero y trasero (*wheelbase*) con el ancho total del vehículo (vía), maximizando la respuesta de la dirección.

> [!IMPORTANT]
> **Iteración del Tren Motriz: De Correas a Engranajes**
> 
> Antes del modelado final, se validaron conceptos espaciales mediante prototipado rápido. Inicialmente, se consideró una transmisión por correa dentada, pero las limitaciones para conseguir bandas a la medida y el riesgo de deslizamiento (*slipping*) obligaron a descartarla. La iteración conceptual consolidó una arquitectura de engranajes cilíndricos de dientes rectos en paralelo. Esto permitió rotar el montaje del motor, empaquetar la transmisión de forma más compacta y confirmar que la reducción longitudinal del chasis era viable.

#### Prototipos Conceptuales Tempranos
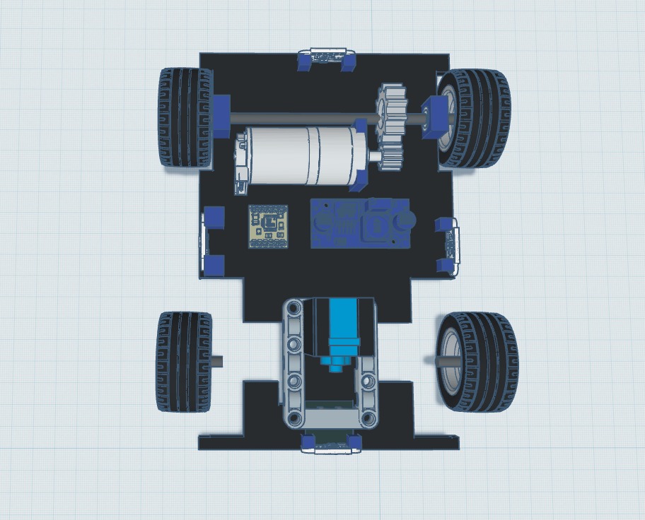
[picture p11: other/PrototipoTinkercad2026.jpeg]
Prototipo Conceptual 1

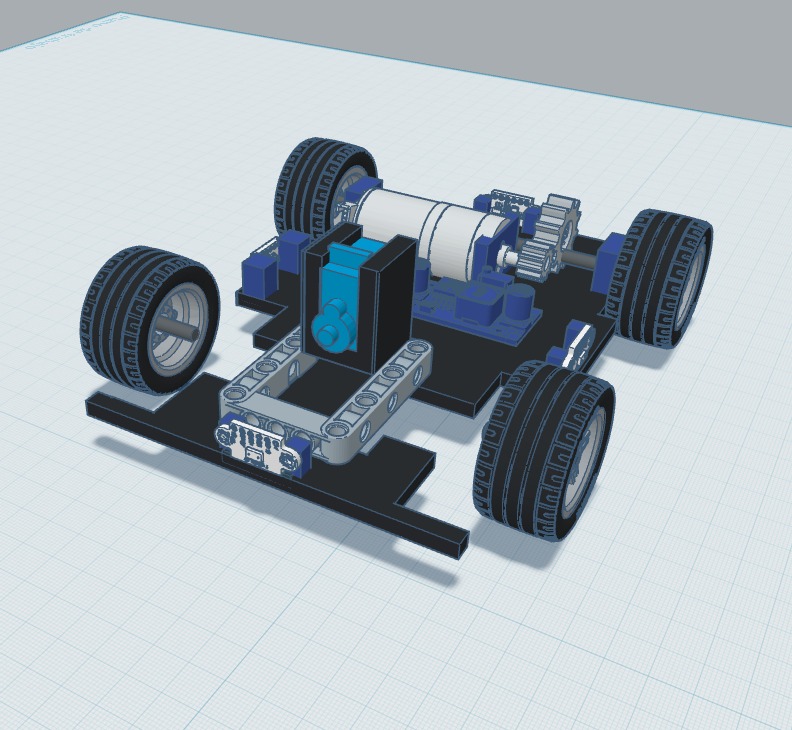
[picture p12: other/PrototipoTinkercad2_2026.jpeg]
Prototipo Conceptual 2

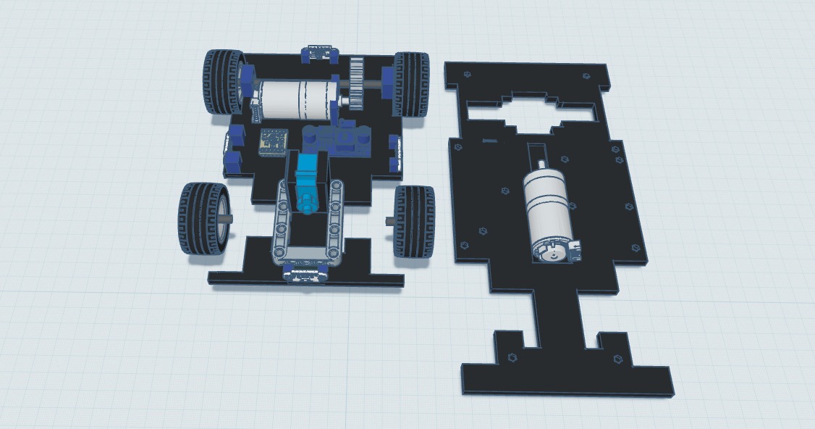
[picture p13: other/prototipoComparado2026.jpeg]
Comparativa de Proporciones


---

### 2. Transición a CAD Profesional y Arquitectura "Monochasis"

Demostrada la viabilidad geométrica, el desarrollo se trasladó al entorno paramétrico de **Onshape**. La innovación estructural radica en la concepción de un **Monochasis** para el nivel inferior: una sola pieza que integra de forma nativa los soportes, canales de cableado y alojamientos mediante operaciones booleanas exactas, erradicando los ensambles múltiples y fijaciones caseras propensas a la vibración.

La plataforma resultante mide **179 mm de largo por 115 mm de ancho**, con una distancia entre ejes de **~112 mm**, cristalizando la relación geométrica 1:1 buscada.

Vista de Planta del Monochasis (Onshape)

#### Desglose Técnico del Tren Motriz (Razonamiento Par/Velocidad)
* **Motor de Tracción:** Modelo JGA25 de 220 RPM con caja reductora metálica. El monochasis incorpora una cama hundida específica para nuestro motor, alineando el eje de salida con la transmisión.
* **Sistema Piñón-Corona:** Un piñón de 15 dientes acoplado al motor transmite la potencia a una corona de 25 dientes. Esta **relación de transmisión de 1.66:1** representa una decisión de ingeniería calculada: sacrifica una fracción de la velocidad final máxima para multiplicar el torque (par motor) entregado a las ruedas, garantizando aceleraciones explosivas y controladas desde el reposo absoluto sin estresar mecánicamente el motor.
* **Eje Trasero (Solución de Taller):** Ante la escasez de varillas calibradas de 4 mm, se adaptaron núcleos de electrodos de soldadura (~2.4 mm). El diámetro se incrementó uniformemente en las zonas de rodadura mediante fundas termocontraíbles, logrando tolerancias de ajuste a presión (*press-fit*) sin holguras.
* **Apoyos y Rodamientos:** El eje descansa sobre rodamientos 604 ZZ ZSG (4x12x4 mm) encajados en portarolineras nativos del chasis.

---

### 3. Validación de Tolerancias y Ensamble Virtual

Antes de realizar la integración completa, el entorno de Onshape nos permitió modelar y auditar cada componente mecánico de forma individual, asegurando que las tolerancias geométricas fueran perfectas.

#### Modelado de Componentes Clave y Sistemas de Anclaje
El diseño del tren motriz requirió la creación de engranajes personalizados, implementando soluciones de fijación específicas para cada tipo de eje:

* **Piñón Motriz (Eje tipo "D"):** Para acoplar el engranaje de 15 dientes al motor JGA25, se aprovechó el corte plano de fábrica del eje metálico. Se modeló un agujero con perfil en "D" calculando tolerancias estrictas para impresión 3D, logrando un ensamble a presión (*press-fit*) perfecto. Esto garantiza la transferencia total de torque sin desgaste y evita que el piñón se desplace o escape por vibración.
* **Corona Conducida (Varilla Lisa):** Para fijar el engranaje de 25 dientes a nuestra varilla trasera adaptada, se implementó un collarín con **sistema de apriete por mordaza tipo "C"**. Al ajustar un tornillo transversal pasante, el collarín se comprime estrangulando la varilla lisa, bloqueando el engranaje mediante fricción radial sin requerir pegamentos ni dañar el metal.

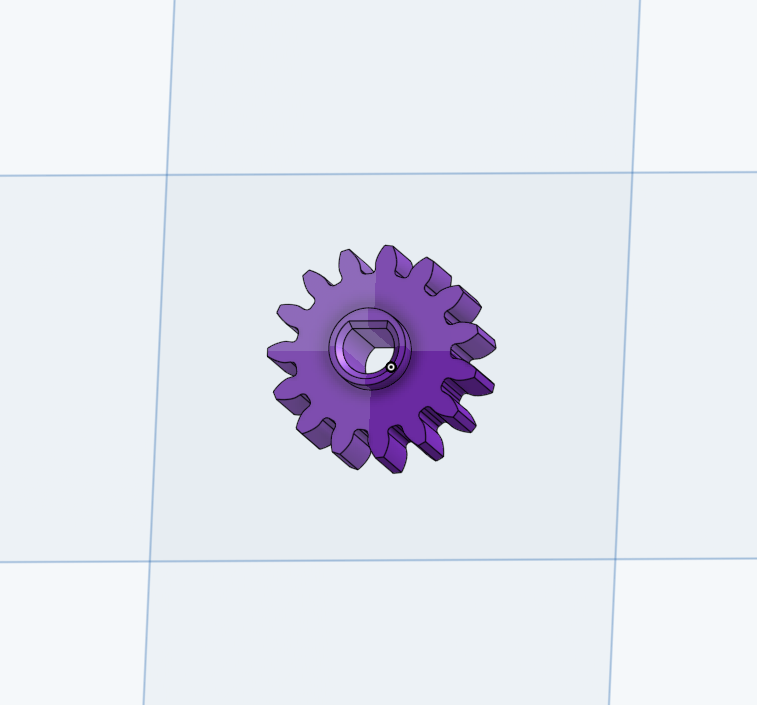
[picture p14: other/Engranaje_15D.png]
Render del Piñón de 15 dientes mostrando el agujero en D
> 
> *Piñón motriz (15T) con acoplamiento tipo D.*

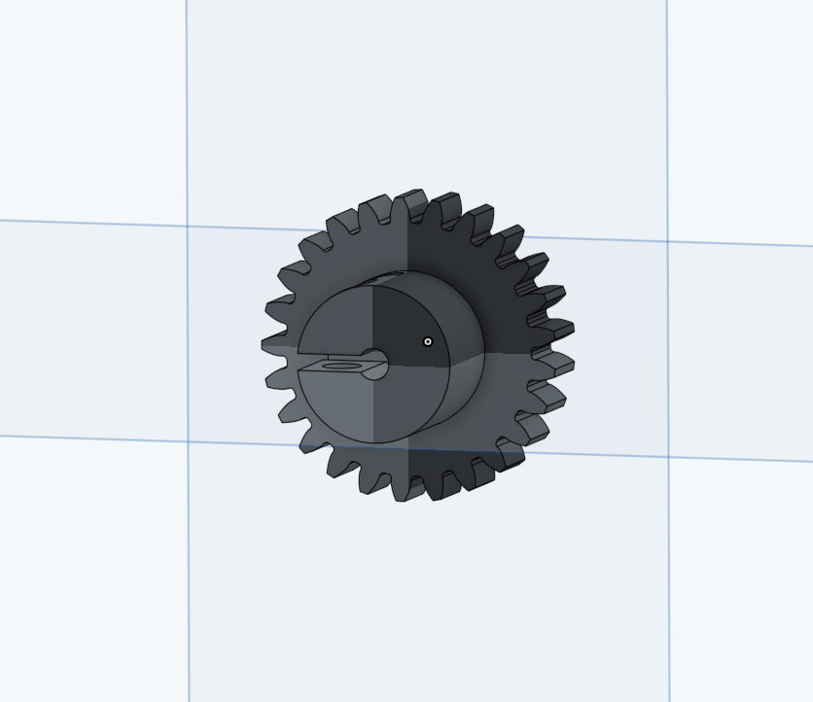
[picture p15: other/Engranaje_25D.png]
Render de la Corona de 25 dientes con mordaza
> 
> *Corona conducida (25T) con sistema de apriete tipo C.*

#### Acoplamiento de Tracción: Adaptador para Ruedas Lego
Para mantener la excelente adherencia a la pista de las **ruedas Lego** heredadas de la iteración pasada y acoplarlas a nuestra nueva varilla de transmisión lisa, se diseñó una interfaz mecánica a medida. 
Este componente de transición cuenta con el perfil transversal clásico en cruz de Lego en un extremo, mientras que la base cilíndrica replica el mismo **sistema de apriete por mordaza tipo "C"** utilizado en la corona. Esto permite fijar la rueda sólidamente a la varilla y facilita enormemente el cambio rápido de neumáticos o mantenimientos en los pits.

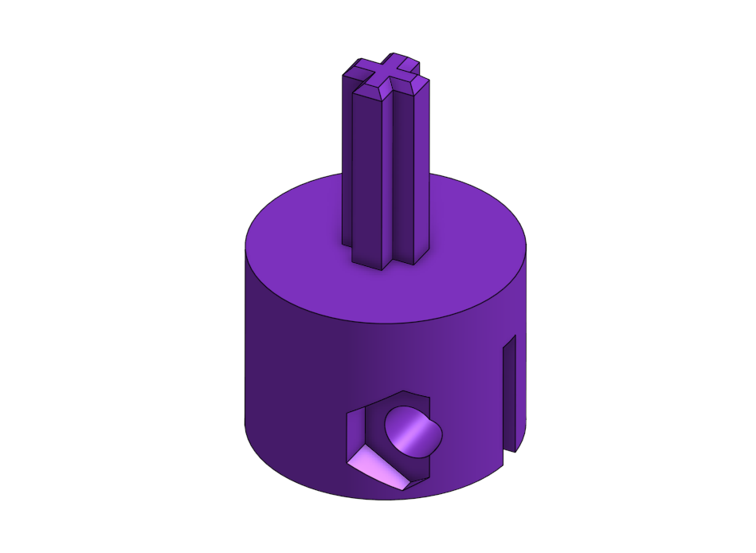
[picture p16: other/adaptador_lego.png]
Vista lateral del adaptador morado con el eje Lego
> 
> *Perfil del adaptador de transición.*

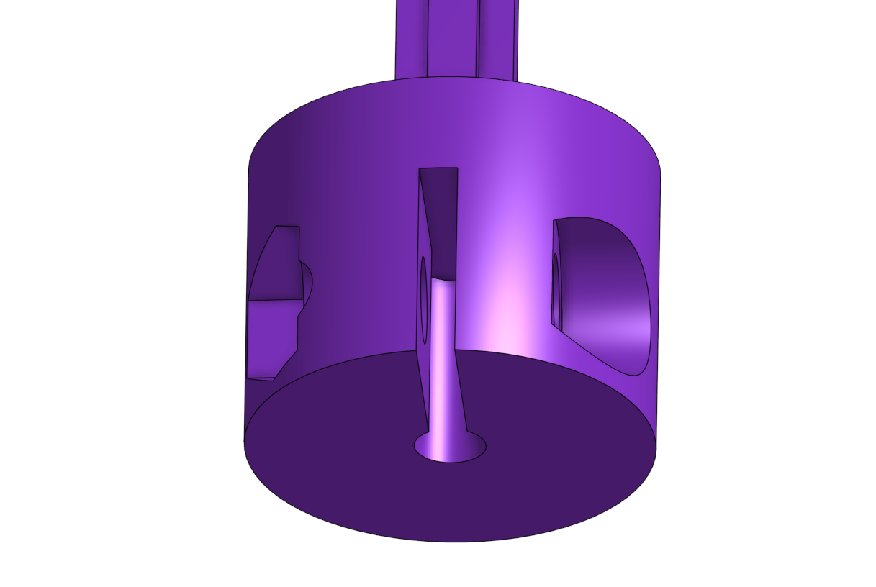
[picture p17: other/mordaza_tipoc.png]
Vista isométrica del adaptador morado mostrando la mordaza tipo C
> 
> *Detalle del sistema de apriete por mordaza transversal.*

#### Ensamble Virtual y Mitigación de Fallos
Una vez validados los componentes individuales, el ensamble virtual completo fue vital para analizar interferencias mecánicas y optimizar el diseño antes de la manufactura. 

> [!TIP]
> **Mitigación de Fallos: Rediseño al soporte de motor**
> 
> Durante la simulación, se detectó que el soporte del motor tenía los tornillos que anclan al motor ubicados en un punto donde serían cubiertos por la corona del eje trasero. Esto obligaría a desmontar la varilla y casi todo el sistema de tracción para sacar el motor, ocasionando pérdidas de tiempo críticas durante mantenimientos en los pits. Para solucionarlo, se reubicaron los agujeros de anclaje hacia las esquinas expuestas del soporte, permitiendo la extracción rápida del motor con solo retirar el piñón. 

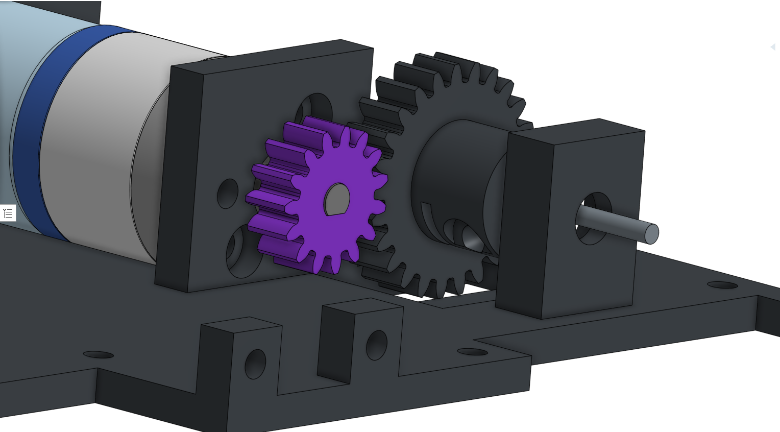
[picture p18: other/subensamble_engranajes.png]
Subensamble del motor acoplado a sus engranajes y la varilla
> 
> *Análisis de interferencia del tren de engranajes.*

> Vista general de la parte trasera del chasis con la propulsión montada
> *Bloque motriz empaquetado y listo para integración.*

---

### 4. Segundo Piso, Separadores y Sistema de Visión "Shark Fin"

El segundo nivel de la plataforma tiene como objetivo distribuir la masa, proteger la electrónica y alojar el robusto sistema de visión computacional.

> [!NOTE]
> **Compensación de Diseño (*Trade-off*) del Centro de Gravedad**
> 
> En versiones anteriores, la batería se ubicaba precariamente en la zona superior. El nuevo diseño integró un compartimento ventilado **debajo del primer piso**. Aunque reduce ligeramente la altura libre al suelo (*ground clearance*), esta compensación baja drásticamente el centro de gravedad (CoG), evitando el balanceo o vuelco en curvas a alta velocidad.

> Vista inferior del chasis mostrando el compartimento de la batería

#### Separadores Estructurales e Insertos Roscados
Para mantener la distancia entre el primer y segundo piso, se modelaron **separadores a medida de 60 mm**. Conscientes de las limitaciones físicas de las impresoras 3D convencionales (que no pueden imprimir micro-roscas funcionales que resistan tracción repetitiva), descartamos roscar el plástico. En su lugar, se insertaron por calor **insertos roscados de latón M3** en cada extremo del separador, logrando pilares de altísima resistencia estructural.

#### Sistema de Sujeción del Teléfono (Mordaza Ajustable)
Para soportar el teléfono celular, se modelaron dos torres aerodinámicas laterales tipo **aleta de tiburón (*Shark Fin*)**. Para garantizar que estas torres no cedieran ante la vibración, se aplicó un método de anclaje de grado industrial:
* **Fijación a la base:** Cada torre aloja en su base inferior **3 insertos roscados de latón**. Los tornillos atraviesan el segundo piso de abajo hacia arriba, traccionando la torre fuertemente contra la plataforma.
* *Nota de Diseño (DfAM):* Para que la termofijación de estos insertos fuera perfecta, se modelaron agujeros ciegos con dimensiones precisas de **4.1 mm de diámetro por 9 mm de profundidad**. Estas tolerancias permiten que el inserto entre, y que el plástico derretido fluya por su moleteado exterior sin rebasar hacia el interior de la rosca.

> [!IMPORTANT]
> **Iteración del Sistema Shark Fin: De Ángulo Fijo a Ángulo Ajustable**
>
> El sistema Shark Fin **no fue diseño directo**: pasó por una primera versión funcional pero limitada antes de llegar al mecanismo actual.
>
> - **Versión 1 (soporte fijo):** Las dos torres laterales sostenían la mordaza fija mediante un soporte rígido, sin posibilidad de variar el ángulo de inclinación del teléfono una vez montado. Cualquier ajuste de encuadre de cámara requería desmontar y modificar físicamente la pieza.
> - **Versión 2 (soporte ajustable, actual):** Se eliminó el soporte fijo y se reemplazó por un tornillo que atraviesa cada torre desde el exterior y aprieta contra la base de la mordaza fija. Al aflojar el tornillo, la base pivota libremente permitiendo recalibrar el ángulo de la cámara en campo; al apretarlo, la inclinación queda bloqueada con fricción mecánica.
>
> Fue un cambio sencillo — un tornillo pasante en lugar de un soporte rígido — pero con alto impacto: permite recalibrar el encuadre de la cámara en segundos durante los pits, sin herramientas adicionales ni reimpresión de piezas.

El mecanismo de retención en sí no es una ranura estática, sino una **Prensa/Mordaza ajustable**:
1. **Calibración de Ángulo:** Las dos torres sostienen una **mordaza fija** central. Esta mordaza está sujeta por tornillos laterales (que encajan en dos insertos roscados propios). Al aflojarlos, la base completa pivota permitiendo ajustar el ángulo de la cámara; al apretarlos, la inclinación queda bloqueada.
2. **Apriete de Seguridad:** La mordaza fija actúa como guía para una **mordaza móvil** interior. En la parte superior de la base fija se modeló una rosca ensanchada a **M10.5** (dejando 0.5 mm de holgura calculada para compensar la contracción térmica del PETG). Por allí desciende un robusto **tornillo M10 impreso en 3D**. Al girarlo, empuja la mordaza móvil hacia abajo de forma perfectamente lineal y confinada, comprimiendo y asegurando el teléfono inteligente con fuerza mecánica sin riesgo de escape.

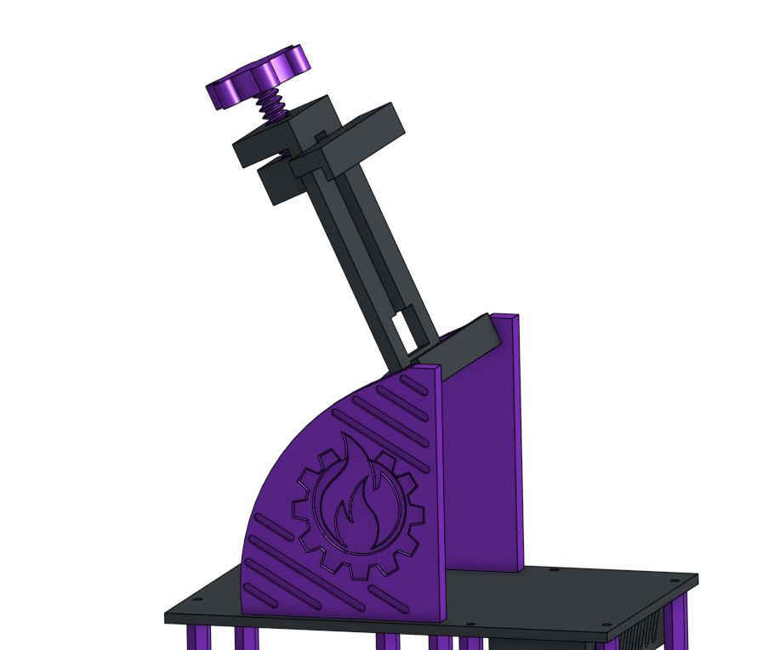
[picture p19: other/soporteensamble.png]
Ensamble completo del soporte Shark Fin
> 
> *Ensamble del soporte Shark Fin interactuando con las torres laterales.*

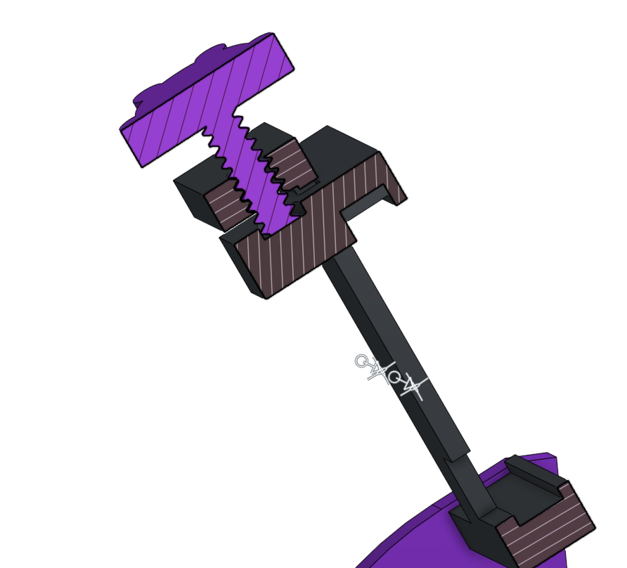
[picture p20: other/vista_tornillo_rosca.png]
Detalle del tornillo M10 superior impreso en 3D
> 
> *Tornillo M10 personalizado y rosca M10.5 de compensación térmica.*

---

### 5. Integración Total: Ensamble Maestro CAD

Con todos los subsistemas (tracción, suspensión de cámara y chasis estructural) modelados y validados individualmente para evitar colisiones mecánicas, el proceso de diseño en Onshape culmina en un Ensamble Maestro. Esta auditoría virtual final nos permite garantizar la accesibilidad a los puertos de los microcontroladores y confirmar visualmente el cumplimiento de las metas geométricas establecidas para la competencia.

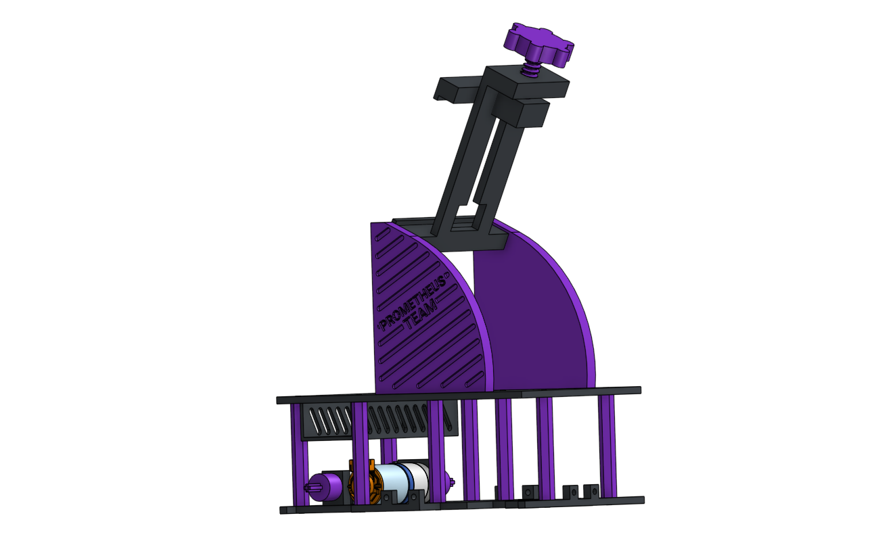
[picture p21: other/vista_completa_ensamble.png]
Vista isométrica general de todo el chasis ensamblado en 3D
> 
> *Perspectiva global del Prometheus Autónomo consolidado en el entorno de simulación.*

---

### 6. Ingeniería de Manufactura Aditiva 

La fabricación se ejecutó aprovechando la estabilidad térmica de la **Creality K1C** y posteriormente en la **Elegoo Centauri Carbon 2**, procesando el modelo en filamento **PETG** a través de Orca Slicer y Elegoo Slicer. Dado que el chasis debe soportar impactos y vibraciones mecánicas constantes, se estableció un perfil de extrusión orientado a la resistencia estructural (*DfAM - Design for Additive Manufacturing*):

| Parámetro de Laminación | Valor | Justificación Técnica (*Trade-off*) |
| :--- | :--- | :--- |
| **Temp. de Boquilla** | 260 °C | Maximiza la fluidez y la fuerza intermolecular (*layer adhesion*). |
| **Flujo Volumétrico Máx.** | 11 - 12 mm³/s | Actúa como gobernador automático de presión en el extrusor. |
| **Velocidad de Relleno** | 150 mm/s | Previene el desgaste del engranaje del extrusor en pases largos. |
| **Perímetros Exteriores** | 5 Paredes | Crea una corteza estructural que resiste la torsión mecánica. |
| **Ventilador de Capa** | 0% inicial / 40% Máx | Compensación crítica: Reduce la estética de los voladizos pero asegura que las capas no se delaminen por enfriamiento prematuro. |
| **Cabina (Enclosure)** | Abierta | Evita la fluencia térmica (*heat creep*) en la garganta del fusor. |

#### Optimizaciones de Impresión:
* **Ensamblaje por Clavijas (*Dowels*):** Las geometrías con voladizos extremos fueron cortadas e impresas de forma plana. Su unión se garantizó mediante clavijas guía cilíndricas de 2.5 mm con tolerancias de 0.15 mm para ajuste deslizante (*slip-fit*), reforzadas con cianocrilato.
* **Gestión Térmica de Micro-componentes:** Las piezas pequeñas se laminaron simultáneamente junto a las grandes. El viaje del cabezal sirvió como ventana de enfriamiento pasivo, evitando la deformación por calor acumulado, apoyadas por un borde exterior (*Brim*) de 5 mm para anclaje a la cama.

---

### Dimensiones Finales y Resumen de Logros Estructurales

| Parámetro Geométrico | Dimensión Físico | Estado |
| :--- | :--- | :--- |
| **Largo Total** | 179 mm | Optimizado |
| **Ancho Total (Vía)** | 115 mm | Optimizado |
| **Distancia entre Ejes** | 112 mm | ~1:1 |

**Evolución Mecánica (2025 vs 2026):**
* **✓ Maniobrabilidad:** Reducción de la cota longitudinal, logrando un ratio de giro excepcional.
* **✓ Tracción Controlada:** Transmisión re-calculada a 1.66:1 para priorizar el torque sobre la velocidad pico y reutilización eficiente de ruedas Lego mediante un adaptador DfAM.
* **✓ Robustez Material:** Transición de fijaciones empíricas a un Monochasis paramétrico en PETG consolidado y separadores de 60 mm con termofijación de latón.
* **✓ Visión y CoG:** Descenso del compartimento energético (batería) y un sistema "Shark Fin" tipo prensa que asegura tolerancias críticas y previene holguras en el dispositivo de cámara.

---

## ⚖️ Análisis de Masa y Distribución de Peso
 
Uno de los efectos directos de la transición del chasis heredado hacia la arquitectura **Monochasis** fue la reducción de masa estructural, verificada empíricamente en báscula tras el ensamblaje final. Es importante distinguir **dos etapas dentro de la propia versión 2025**, ya que el chasis heredado ganó masa de forma significativa entre su impresión inicial y su configuración final de competencia:
 
| Etapa | Con smartphone | Sin smartphone |
| :--- | :---: | :---: |
| **v1 — Chasis 3D recién impreso** (sin trípode ni contrapesos) | 943 g | 763 g |
| **v1 — Chasis 3D final de competencia** (+ bastón trípode + contrapesos de plomo) | **≈1300 g** | ≈1120 g |
| **v2 — Monochasis actual (2026)** | **1092 g** | **861 g** |
 
| Comparación | Con smartphone | Sin smartphone |
| :--- | :---: | :---: |
| v2 (2026) vs. v1 final de competencia (2025) | 🔻 −208 g (−16.0 %) | 🔻 −259 g (−23.1 %) |
 
> [!IMPORTANT]
> **El verdadero costo del sistema trípode + contrapeso**
>
> La comparación correcta no es contra los 943 g de la impresión inicial de v1 (que **no** incluía aún el sistema trípode), sino contra su configuración final de competencia de **≈1.3 kg**. El bastón del trípode y, sobre todo, los contrapesos de plomo añadidos para compensar el efecto de palanca (ver diario de ingeniería) le agregaron cerca de **360 g** al chasis heredado — casi un tercio de su masa sin teléfono. Esto confirma que el sobrepeso de v1 no era un problema de diseño estructural per se, sino el costo acumulado de mitigar con masa adicional (contrapesos) un defecto geométrico (flexión por palanca) que v2 resolvió de raíz mediante el rediseño de proporciones 1:1, sin necesitar ningún contrapeso.
 
> [!NOTE]
> **Compensación de Diseño (*Trade-off*): Peso vs. Rigidez**
>
> La reducción de hasta 259 g respecto a la versión final de 2025 se logró **sin sacrificar rigidez estructural**, a pesar de que el Monochasis integra en una sola pieza soportes, canales de cableado y alojamientos que antes requerían múltiples piezas ensambladas. La eliminación de refuerzos improvisados (silicón, agujeros correctivos, contrapesos de plomo) es la principal responsable de esta reducción, más que un adelgazamiento deliberado de paredes.
 
### Distribución de Masa Estática (Eje Delantero / Eje Trasero)
 
Con el smartphone montado en el sistema *Shark Fin*, se realizó una medición independiente por eje para caracterizar el centro de gravedad longitudinal del vehículo:
 
| Eje | Masa Medida | Distribución |
| :--- | :---: | :---: |
| **Delantero** | 660 g | **54.5 %** |
| **Trasero** | 550 g | **45.5 %** |
| **Total (config. de medición)** | 1210 g | 100 % |
 
```mermaid
pie showData
    title Distribución de Masa Estática por Eje
    "Eje Delantero (54.5%)" : 660
    "Eje Trasero (45.5%)" : 550
```
 
> [!IMPORTANT]
> **Justificación de Ingeniería**
>
> El ligero sesgo hacia el eje delantero (≈9 puntos porcentuales por encima del reparto ideal 50/50) es consistente con el diseño: el teléfono y el sistema *Shark Fin* — los componentes más pesados montados en altura — están ubicados sobre el segundo piso hacia la zona delantera-media, mientras que la batería LiPo se reubicó **debajo del primer piso** (ver sección de *Trade-off* del centro de gravedad) precisamente para compensar y bajar el CoG global, sin eliminar por completo el sesgo delantero. Este reparto favorece la tracción en frenado y la respuesta de la dirección delantera, aunque exige que el motor trasero entregue suficiente torque para no perder agarre en la aceleración — lo cual se valida en la siguiente sección.

---

## 🚀 Cálculo de Velocidad, Torque y Margen de Seguridad

Para garantizar que el vehículo cuente con la agilidad y fuerza necesarias en la pista, se calcularon teóricamente la velocidad lineal y los requerimientos de torque del tren motriz basándonos en la masa actual del vehículo en configuración de competencia (incluyendo el smartphone).

### 1. Cálculo de la Velocidad Lineal del Vehículo
El motor empleado (25GA-370) tiene una velocidad nominal de 220 RPM en el eje de salida. Convertimos esta velocidad a radianes por segundo ($\omega$):

$$\omega = \frac{220 \cdot 2\pi}{60} \approx 23.04 \text{ rad/s}$$

Con un radio de rueda ($r$) de 0.04 m, la velocidad lineal teórica ($v$) del vehículo es:

$$v = \omega \cdot r = 23.04 \cdot 0.04 \approx 0.92 \text{ m/s}$$

### 2. Cálculo de Torque Necesario y Disponible
El torque necesario ($T_{\text{necesario}}$) para mover el vehículo desde el reposo absoluto se calcula mediante la fórmula:

$$T_{\text{necesario}} = m \cdot g \cdot r$$

Donde:
* $m$ = masa del vehículo actual con smartphone (1.092 kg)
* $g$ = gravedad (9.81 $\text{m/s}^2$)
* $r$ = radio de las ruedas (0.04 m)

$$T_{\text{necesario}} = 1.092 \cdot 9.81 \cdot 0.04 \approx 0.429 \text{ N·m}$$

Por otro lado, el motor 25GA-370 con su caja reductora integrada (21.3:1) entrega un torque de salida ($T_{\text{salida}}$ o disponible) mayor:

$$T_{\text{disponible}} = 0.0343 \text{ N·m (motor base)} \cdot 21.3 \approx 0.7306 \text{ N·m}$$

### 3. Margen de Seguridad de Torque
Con el torque necesario y el torque disponible calculados, se puede cuantificar el margen de seguridad del sistema de tracción como un porcentaje, siguiendo la lógica de un análisis de ingeniería estándar:

$$\text{Margen de Seguridad (\%)} = \frac{T_{\text{disponible}}}{T_{\text{necesario}}} \times 100$$

$$\text{Margen de Seguridad} = \frac{0.7306 \text{ N·m}}{0.429 \text{ N·m}} \times 100 \approx 170.5\%$$

> [!IMPORTANT]
> **Interpretación del margen**
>
> Un valor de 170.5% significa que el tren motriz entrega suficiente potencia para mover el vehículo (1092 g) en condiciones normales, contando con un excedente del **70.5%** por encima del mínimo requerido. Este colchón no es gratuito: se traduce directamente en capacidad de aceleración, tolerancia a superficies con mayor fricción de la esperada y margen ante el desgaste progresivo de los engranajes impresos en 3D, garantizando que el peso extra del teléfono no comprometa la agilidad en la pista.

### 4. Tiempo Teórico de Vuelta vs. Tiempo Real en Pista
A partir de la velocidad lineal máxima calculada ($v = 0.92 \text{ m/s}$), es posible estimar el tiempo teórico que tomaría completar una vuelta a la pista y compararlo contra los tiempos reales medidos en pruebas.

$$\text{Tiempo teórico} = \frac{\text{Distancia recorrida en una vuelta}}{v}$$

$$\text{Tiempo teórico} \approx \frac{9.5 \text{ m}}{0.92 \text{ m/s}} \approx 10.3 \text{ s}$$

| Modo | Tiempo Teórico (v máx. constante) | Tiempo Real Medido (promedio) | Velocidad Real Efectiva | % de la Velocidad Teórica |
| :--- | :---: | :---: | :---: | :---: |
| **Vuelta Libre** | ≈ 10.3 s | **25 s** | ≈ 0.38 m/s | ≈ 41% |
| **Modo Obstáculos** | ≈ 10.3 s (misma distancia base) | **1:20 min (80 s)** | ≈ 0.12 m/s | ≈ 13% |

```mermaid
xychart-beta
    title "Tiempo por Vuelta: Teórico vs. Real"
    x-axis ["Teórico (v máx.)", "Vuelta Libre (real)", "Obstáculos (real)"]
    y-axis "Tiempo (segundos)" 0 --> 90
    bar [10.3, 25, 80]
```

> [!IMPORTANT]
> **Por qué la brecha es esperada (y qué nos dice)**
>
> El tiempo teórico asume velocidad lineal máxima constante durante toda la vuelta, lo cual no ocurre en la práctica: el algoritmo de Vuelta Libre reduce la velocidad al corregir el ángulo con el BNO055 y al ajustar la distancia de seguridad respecto al muro antes de cada intersección, mientras que en Modo Obstáculos se suman las desaceleraciones necesarias para detectar, clasificar y esquivar cada pilar. La caída al ~41% de la velocidad teórica en vuelta libre es consistente con un algoritmo que prioriza precisión de trayectoria sobre velocidad pico; la caída adicional a ~13% en obstáculos confirma que el cuello de botella no es mecánico (el motor tiene margen de torque de sobra, ver sección anterior) sino de tiempo de procesamiento y maniobra en el modo de evasión.

## 🔵 Coeficiente de Fricción y su Rol en el Cálculo de Tracción
 
Para validar el margen de torque calculado en la sección de transmisión, es necesario cuantificar la fuerza de fricción disponible entre las ruedas Lego Technic y la superficie de la pista (tapiz tipo alfombra/goma reglamentario de WRO).
 
$$F_{friccion} = \mu \cdot N$$
 
Donde:
- **μ (coeficiente de fricción estático rueda–tapiz):** se estima en un rango de **0.6 – 0.8**, valor típico documentado para neumáticos de goma Lego Technic sobre superficies texturizadas similares al tapiz de competencia (no se dispone de tribómetro, por lo que se usa un rango de referencia en lugar de un valor único).
- **N (fuerza normal sobre el eje motriz):** derivada directamente de la distribución de masa medida — **550 g × 9.81 m/s² ≈ 5.4 N** sobre el eje trasero (motriz).

| Escenario | μ | Fuerza de fricción máxima disponible (eje trasero) |
| :--- | :---: | :---: |
| Conservador | 0.6 | ≈ 3.24 N |
| Óptimo | 0.8 | ≈ 4.32 N |
 
> [!TIP]
> **Por qué este dato importa**
>
> Este cálculo cierra el ciclo de validación del tren motriz: no basta con que el motor tenga torque suficiente en el eje (ya calculado previamente con el margen de seguridad), también hay que confirmar que **la fricción disponible no sea el factor limitante** antes que el propio motor. Como la fuerza de fricción máxima (3.24–4.32 N) es mayor que la fuerza de tracción requerida para la aceleración objetivo del vehículo, se confirma que el sistema está limitado por el torque del motor y no por pérdida de agarre — es decir, el diseño está correctamente dimensionado y no derrapará antes de alcanzar su velocidad de operación.
 
---
 
## ⚙️ Alternativas de Transmisión Evaluadas: Piñón-Corona vs. Correa Dentada
 
Antes de consolidar la relación de transmisión 1.66:1 mediante engranajes cilíndricos, se evaluó formalmente una arquitectura alternativa por correa dentada, descartada por las siguientes razones técnicas:
 
| Criterio | 🟢 Piñón-Corona (elegido) | 🔴 Correa Dentada (descartado) |
| :--- | :--- | :--- |
| **Precisión de relación de transmisión** | Exacta y constante (contacto positivo diente-diente) | Variable — susceptible a **deslizamiento (*slipping*)**, degrada la relación real bajo carga |
| **Disponibilidad de repuestos (Venezuela)** | Alta — fabricables bajo demanda en impresora 3D propia | Baja — bandas de medida específica difíciles de conseguir localmente |
| **Comportamiento bajo carga** | Estable — la masa del vehículo (861–1092 g) no compromete el engrane | Riesgo de ruptura de la banda ante la masa considerable del vehículo |
| **Sensibilidad al ajuste/tensado** | Ninguna — el engrane no requiere tensión externa | Crítica — tensión insuficiente causa deslizamiento; tensión excesiva daña los ejes |
| **Mantenibilidad en pits** | Alta — reemplazo rápido, tolerancias impresas conocidas | Baja — requiere retensado fino cada vez que se manipula |
| **Costo de iteración de diseño** | Bajo — un nuevo piñón/corona es una reimpresión | Alto — depende de terceros para conseguir banda a medida |
 
> [!IMPORTANT]
> **Conclusión de Ingeniería**
>
> La transmisión por engranajes ofrece **acoplamiento positivo** (sin elemento elástico intermedio), lo que elimina cualquier pérdida de sincronía entre la rotación del motor y la rotación de las ruedas — una propiedad crítica para que el algoritmo de navegación autónoma (que depende de la relación de transmisión conocida para sus cálculos de velocidad lineal) sea determinístico. Adicionalmente, al ser una pieza 100% fabricada in-house, el equipo controla directamente las tolerancias de cada diente, iterando el diseño en horas en lugar de depender de la cadena de suministro local — un factor decisivo en un país donde la disponibilidad de componentes específicos (como bandas dentadas a medida) es limitada.
 
---
 
## 📓 Diario de Ingeniería: Evolución del Chasis (v0 → v2)
 
Esta sección documenta el historial completo de fallos y rediseños que llevaron a la arquitectura Monochasis actual, siguiendo la metodología de diagnóstico → causa raíz → mitigación.
 
```mermaid
flowchart TD
    A["🟤 v0 — Prototipo de Cartón<br/>(validación geométrica de<br/>transmisión trasera y dirección Lego)"] -->|"Flexión del material,<br/>zonas ablandadas,<br/>desgaste por uso"| B["🖨️ v1 — Chasis 3D Impreso<br/>(impreso por terceros, sin<br/>iteración propia)"]
    B -->|"Diagnóstico: chasis excesivamente<br/>largo por sistema trípode"| C{"⚠️ Fallas Detectadas en v1"}
    C --> C1["Flexión central del chasis<br/>(efecto palanca del bastón<br/>del trípode)"]
    C --> C2["Motor trasero orientado<br/>verticalmente → alto<br/>consumo de espacio"]
    C --> C3["Ensamblaje no modular:<br/>silicón, agujeros correctivos,<br/>lijado manual"]
    C1 --> D["🔧 Mitigación temporal v1:<br/>contrapesos de plomo cerca<br/>del eje trasero"]
    C2 --> E["📏 Rediseño geométrico:<br/>objetivo de relación 1:1<br/>(wheelbase = vía)"]
    C3 --> F["🔩 Rediseño para modularidad:<br/>tornillería Allen M3 en<br/>toda la plataforma"]
    D --> G["✅ v2 — Monochasis Actual<br/>(179×115 mm, eje 112 mm,<br/>motor horizontal, desmontable)"]
    E --> G
    F --> G
```
 
### 🟤 Iteración v0 — Prototipo de Cartón
 
| | |
| :--- | :--- |
| **Objetivo** | Validar el encaje físico del sistema de transmisión trasera y del sistema de dirección delantera, ambos construidos con piezas Lego, antes de comprometerse a un diseño CAD definitivo. |
| **Método** | Iteraciones sucesivas de la base de cartón, ajustando medidas hasta lograr el encaje perfecto de ambos subsistemas. |
| **Diagnóstico de falla** | Tras varias pruebas, el cartón mostró **flexión notable**, zonas ablandadas por humedad/uso y síntomas generales de fatiga de material — comportamiento esperado de un material concebido como *placeholder* temporal. |
| **Causa raíz** | El cartón nunca fue seleccionado como material estructural final; su función fue exclusivamente geométrica (definir medidas de encaje), no mecánica. |
| **Lección aprendida** | Las medidas validadas en cartón se trasladaron directamente a un entorno CAD para la siguiente iteración, evitando repetir el proceso de prueba-error en un material sin capacidad de carga real. |
 
### 🖨️ Iteración v1 — Primer Chasis Impreso en 3D
 
| | |
| :--- | :--- |
| **Objetivo** | Materializar en un material rígido las medidas validadas en cartón, e incorporar un sistema trípode para elevar la posición del teléfono. |
| **Diagnóstico de falla #1 — Flexión estructural** | El chasis, al ser excesivamente largo, presentó flexión notoria en la zona media. |
| **Causa raíz #1** | El bastón central del sistema trípode actuaba como **palanca**, empujando el chasis hacia adelante y concentrando el esfuerzo flector en el punto medio de la plataforma. |
| **Mitigación #1 (parche, no solución de raíz)** | Se rellenaron tapas de tubería con plomo para usarlas como contrapeso, colocándolas cerca del eje trasero para contrarrestar el desbalance de masa generado por el trípode. Este parche, sumado al propio bastón del trípode, elevó la masa total del chasis de 943 g a **≈1300 g** (+357 g), evidenciando que se estaba corrigiendo un problema geométrico agregando masa en lugar de resolver la causa estructural. |
| **Diagnóstico de falla #2 — Empaquetamiento ineficiente** | El sistema de tracción trasero, aunque contaba con diferencial, orientaba el motor **verticalmente** respecto al eje trasero en lugar de en paralelo horizontal. |
| **Causa raíz #2** | Esta orientación consumía un volumen de chasis significativamente mayor al necesario, restando espacio útil para electrónica y cableado. |
| **Diagnóstico de falla #3 — Baja mantenibilidad** | El chasis requirió múltiples intervenciones correctivas post-impresión: agujeros extra, lijado y fijación de piezas con silicón. |
| **Causa raíz #3** | El diseño se envió a imprimir con un proveedor externo (el equipo no contaba con impresora 3D propia en ese momento), lo que impedía iterar rápidamente sobre el modelo CAD y corregir errores de diseño antes de fabricar — cada corrección debía resolverse manualmente sobre la pieza ya impresa. |
| **Lección aprendida** | Un ensamblaje que depende de adhesivos y ajustes manuales post-impresión no es reproducible ni mantenible en condiciones de competencia (pits). Esta experiencia motivó dos decisiones de diseño explícitas para v2: (1) diseñar con tolerancias correctas desde el CAD para evitar reprocesos, y (2) estandarizar toda la sujeción con tornillería Allen M3 desmontable. |
 
### ✅ Iteración v2 — Monochasis (Versión Actual, 2026)
 
| | |
| :--- | :--- |
| **Objetivo de diseño** | Corregir simultáneamente los tres fallos de v1: flexión estructural, empaquetamiento ineficiente del tren motriz y baja mantenibilidad. |
| **Solución a la flexión** | Reducción deliberada de la longitud del chasis (relación de aspecto ≈1:1, wheelbase 112 mm) para eliminar el brazo de palanca que causaba la flexión en v1 — ya no es necesario ningún contrapeso correctivo. |
| **Solución al empaquetamiento** | Reorientación del motor a posición **horizontal, paralela al eje trasero**, integrada nativamente en el Monochasis mediante una cama hundida diseñada específicamente para el motor JGA25. |
| **Solución a la mantenibilidad** | Toda la plataforma se ensambla con **tornillería Allen M3** sobre insertos roscados de latón termofijados, eliminando por completo el uso de silicón y permitiendo el desmontaje de cualquier componente sin herramientas especiales ni reprocesos manuales. |
| **Resultado medible** | Masa reducida en 82 g respecto a v1 (943 g → 861 g) a pesar de integrar más funcionalidad en una sola pieza, confirmando que la ganancia no vino de adelgazar paredes sino de eliminar refuerzos correctivos. |

 ---

### Margen de Seguridad de Torque

Con el torque necesario y el torque disponible ya calculados, se puede cuantificar el margen de seguridad del sistema de tracción como un porcentaje, siguiendo la misma lógica que un análisis de ingeniería estándar:

$$\text{Margen de Seguridad (\%)} = \frac{T_{\text{disponible}}}{T_{\text{necesario}}} \times 100$$

$$\text{Margen de Seguridad} = \frac{0.7306 \text{ N·m}}{0.370 \text{ N·m}} \times 100 \approx 197.5\%$$

> [!IMPORTANT]
> **Interpretación del margen**
>
> Un valor de 197.5% significa que el tren motriz entrega **casi el doble** del torque mínimo requerido para mover el vehículo (943 g) en condiciones normales — un excedente del **97.5%** por encima del mínimo. Este colchón no es gratuito: se traduce directamente en capacidad de aceleración, tolerancia a superficies con mayor fricción de la esperada y margen ante el desgaste progresivo de los engranajes impresos en 3D, sin necesidad de sobredimensionar el motor ni aumentar el consumo eléctrico.
</markdown>

---

## 🛠️ Guía de Ensamble Paso a Paso

Uno de los pilares fundamentales en la ingeniería y un criterio clave de evaluación en la WRO es la **reproducibilidad**. Por ello, hemos diseñado esta guía de ensamblaje para documentar el proceso de construcción de nuestro vehículo, compartiendo consejos prácticos, técnicas de taller y consideraciones mecánicas que facilitarán la replicación exacta de este proyecto a cualquier otro equipo o desarrollador.

---

### Paso 1: Manufactura Aditiva (Impresión 3D)
El primer paso es imprimir todas las piezas estructurales detalladas en los archivos del repositorio. Aunque hemos documentado nuestros parámetros de impresión ideales en la sección anterior, siéntete libre de jugar con estas configuraciones para adaptarlas al comportamiento específico de tu impresora o al material que utilices. 

> [!TIP]
> **Consejo de impresión para transmisión:** 
> Para los engranajes y poleas mecánicas, es vital garantizar la máxima resistencia estructural. Si imprimes en PETG, te recomendamos ajustar la temperatura al alza y aumentar considerablemente el número de perímetros/paredes; esto evitará que los dientes se fracturen bajo el torque del motor.

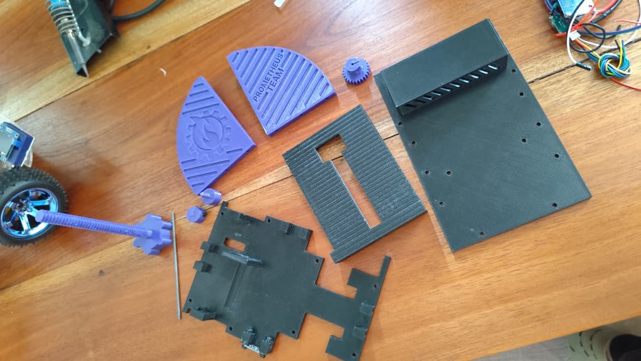
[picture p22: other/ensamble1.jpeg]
Impresión de piezas


---

### Paso 2: Instalación del Motor y Piñón en el Monochasis
Con las piezas listas, comenzaremos a trabajar sobre el chasis (primer piso). 
1. Fija el motor a su cama nativa utilizando tornillos M3. **Detalle crucial:** asegúrate de que los conectores eléctricos del motor queden mirando hacia arriba o hacia un costado libre; esto te facilitará enormemente el cableado posterior hacia el driver TB6612FNG.
2. Acopla el engranaje piñón al eje del motor. Entra a presión (*press-fit*). Notarás que el diseño del piñón tiene un lado redondeado y un pequeño separador integrado; esto sirve para que haga tope correctamente y no roce contra la caja reductora del motor. Asegúrate de que quede firme y no sea fácil de extraer.

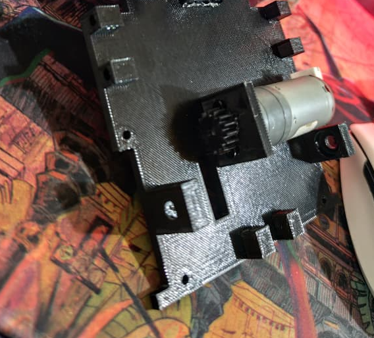
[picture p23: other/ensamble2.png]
Instalación de motor y piñón


---

### Paso 3: Armado del Eje Trasero, Corona y Adaptadores de Rueda
Para el eje motriz, optamos por una solución de taller muy accesible: el núcleo de un electrodo de soldadura limpio. 
1. Como la varilla lisa tiene un diámetro menor al de las rolineras (rodamientos), ensancha su diámetro usando fundas termocontraíbles. 
2. Coloca termocontraíble solo en **un extremo** de la varilla hasta que entre con un poco de presión en la primera rolinera del chasis. 
3. Pasa la varilla por esa primera rolinera, inserta el engranaje corona (25T) en el centro de la varilla, y luego aplica termocontraíble en el otro extremo para pasarlo por la segunda rolinera.
4. Alinea los dientes de la corona con el piñón del motor. Una vez acoplados, inserta un tornillo transversal con su tuerca en el collarín de la corona para apretar el sistema de mordaza tipo "C" y fijarlo a la varilla.
5. Finalmente, instala los adaptadores para las ruedas Lego. Deslízalos en ambos extremos sobresalientes de la varilla y asegúralos con un tornillo y tuerca, utilizando exactamente el mismo mecanismo de mordaza en "C" que empleaste en la corona.

> [!TIP]
> **Pro-Tip de fricción:** 
> Antes de aplicar calor para encoger las fundas sobre el metal, coloca unas gotas de cianocrilato (superglue) entre el metal y el plástico. Esto evitará por completo que el termocontraíble patine o deslice sobre la varilla cuando el motor aplique torque.

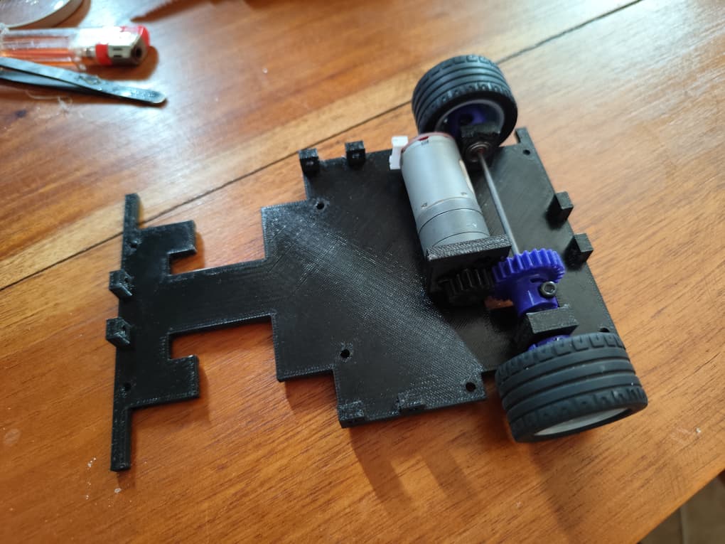
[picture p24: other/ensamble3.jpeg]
Armado del eje trasero


---

### Paso 4: Anclaje del Sistema de Dirección Lego
Toma el subsistema de dirección frontal construido con piezas Lego y ubícalo en el espacio correspondiente del chasis; entrará con un poco de presión. Para asegurar la unión de forma permanente, aplica silicona caliente por los bordes de contacto entre el plástico 3D y las piezas Lego. 

*Nota de ingeniería:* La silicona no solo actúa como adhesivo, sino que al curar mantiene una propiedad gomosa que sirve como un excelente sistema de amortiguación pasiva para absorber las vibraciones de la pista.

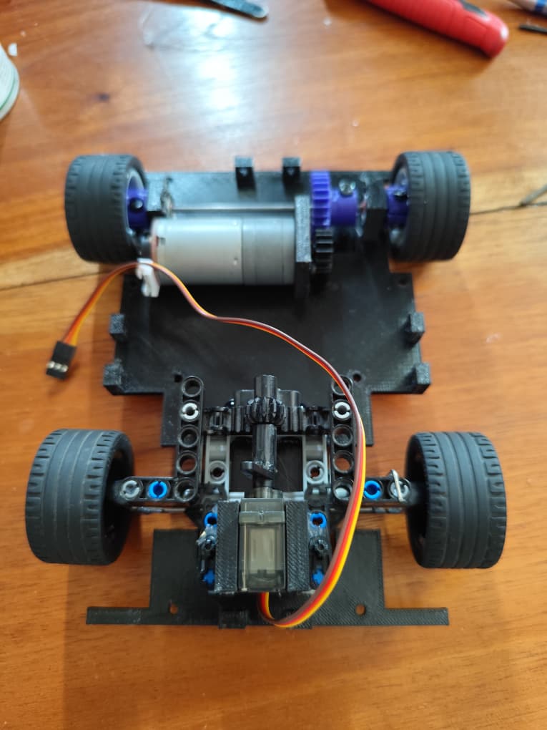
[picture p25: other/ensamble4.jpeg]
Sistema de dirección


---

### Paso 5: Montaje Periférico de Sensores ToF
Alrededor del perímetro del primer piso (Adelante, Atrás, Izquierda y Derecha) encontrarás los alojamientos nativos para los sensores de distancia láser VL53L0X. Fija cada módulo en su soporte utilizando tornillos M3 con sus respectivas tuercas en la parte posterior para asegurar una lectura sin vibraciones.

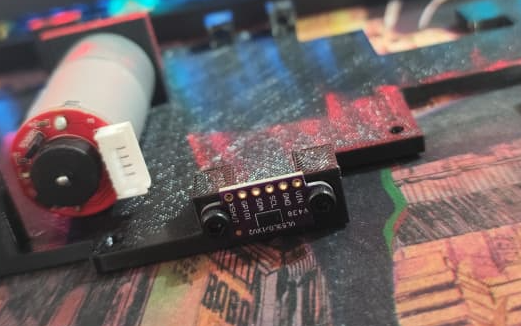
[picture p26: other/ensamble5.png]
Montaje de sensores ToF


---

### Paso 6: Preparación e Instalación de los Separadores
Toma los separadores de 60 mm impresos en 3D e inserta por calor los insertos roscados de latón M3 en cada extremo. Una vez enfriados, ubícalos en sus respectivas posiciones sobre el primer piso y fíjalos introduciendo tornillos M3 desde la cara inferior del chasis. Con esto, el primer nivel queda estructuralmente terminado.

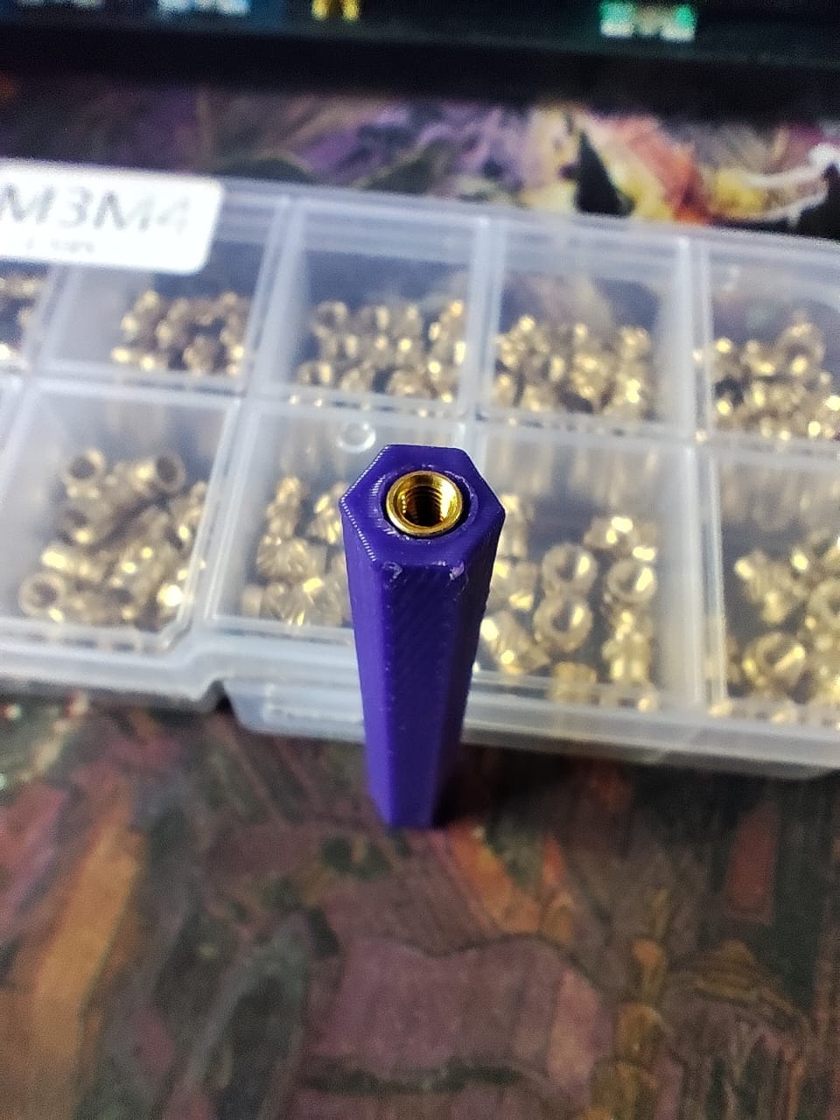
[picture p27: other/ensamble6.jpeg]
Instalación de separadores


---

### Paso 7: Ensamblaje del Sistema *Shark Fin* (Soporte de Cámara)
Antes de unir ambos niveles del vehículo, debemos preparar el segundo piso instalando las torres laterales aerodinámicas (*Shark Fin*) que sostendrán el teléfono inteligente.
1. Inserta por calor 3 insertos roscados M3 en la base de cada torre (6 en total).
2. Alinea las torres con los agujeros pasantes correspondientes en el segundo piso.
3. Introduce los tornillos **desde la parte de abajo** del segundo piso hacia arriba para traccionar fuertemente las torres. 

*(Es precisamente por esta maniobra de atornillado inferior que no podíamos fijar el segundo piso a los separadores en el paso anterior, ya que nos habríamos quedado sin espacio para manipular la herramienta).*

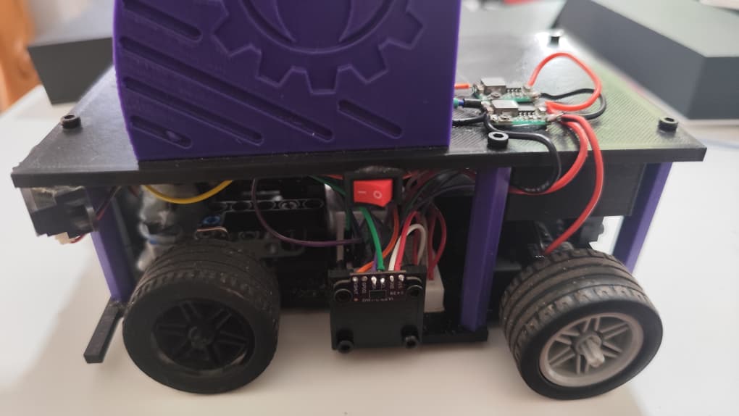
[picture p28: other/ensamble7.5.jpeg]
Soporte Shark Fin


---

### Paso 8: Integración Final de la Plataforma
Con las torres del teléfono ya ancladas sólidamente a su base, puedes proceder a colocar el segundo piso completo sobre los separadores de 60 mm que instalaste en el Paso 6. Asegúralos con tornillos M3 superiores. Finalmente, acopla la mordaza central de ángulo ajustable entre las dos torres para completar el soporte del teléfono y procede con el ruteo del cableado y montaje de la electrónica.

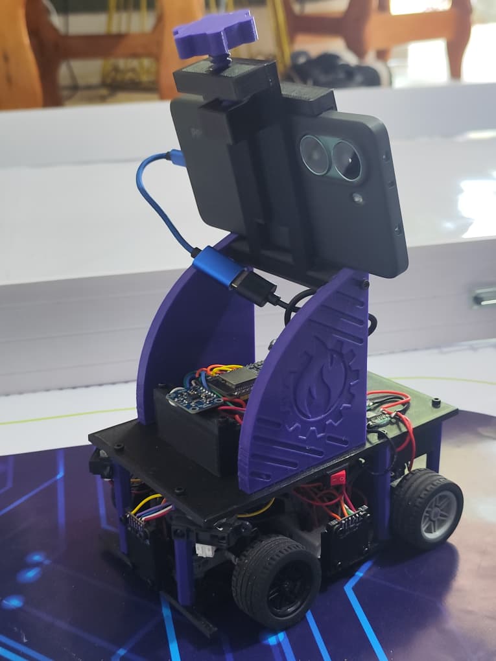
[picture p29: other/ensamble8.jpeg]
Integración final de chasis


## Continuidad en el Desarrollo de Software y Control:
#### Continuidad y Optimización en el Desarrollo de Software: Integración del BNO055

Es importante destacar que la arquitectura del firmware y la lógica de codificación del vehículo mantienen su base estructural respecto a las implementadas con éxito en el diseño del año anterior, garantizando fiabilidad en el procesamiento de datos y control cinemático. 

Sin embargo, la actualización tecnológica más significativa de esta temporada radica en la sustitución del sensor giroscópico por la IMU **BNO055**. Al heredar y refinar la lógica de orientación previa, este nuevo sensor elimina por completo los problemas históricos de deriva (*gyro drift*), volviéndola prácticamente despreciable. El impacto de este cambio en el comportamiento del vehículo es drástico:

* **Consciencia Espacial Absoluta:** El vehículo calcula en tiempo real y de forma fidedigna su vector de orientación angular en todo momento.
* **Estabilización de Carril:** Permite determinar con precisión milimétrica cuándo el chasis se encuentra perfectamente recto en relación con el carril de navegación, optimizando las correcciones del servo de dirección y evitando sobrecorrecciones.

Para explorar a fondo la implementación matemática y el firmware, puedes acceder directamente a las secciones detalladas:
* [Desarrollo de la Lógica de Vueltas a la Pista (Vuelta Libre)](#Desarrollo-de-la-Logica-del-codigo-Maestro)
* [Desarrollo de la Lógica de Evasión de Objetos (Modo Combinado)](#desarrollo-de-la-logica-de-evasion-de-objetos)

---

### 📊 Resumen Ejecutivo de la Lógica de Control

A continuación, se presenta una síntesis operativa de los algoritmos de navegación que gobiernan el firmware mediante el uso de la IMU BNO055 y la lectura periférica de sensores:

#### 1. Modo Vuelta Libre (Navegación de Pista Vacía)
Este algoritmo está diseñado para maximizar la velocidad en pista recta y asegurar trazadas óptimas en las curvas. El sistema prioriza las lecturas angulares de la IMU para la alineación del vehículo.

* **Estrategia:** El sensor ToF lateral mide las distancias relativas hacia la pared guía. Si la orientación calculada por el **BNO055** indica un desvío angular, el sistema ejecuta un control fino corrigiendo en primera instancia el ángulo del vehículo para estabilizarlo y, consecutivamente, ajusta la distancia de seguridad respecto al muro. 
* **Transición de Intersecciones:** El bucle se mantiene activo manteniendo el carril de forma autónoma hasta que el sensor de color detecta una línea en la pista, interrumpiendo el control lineal para ejecutar un giro controlado de intersección.

---

## 📱 Telemetría y Visión Artificial: Aplicación Prometheus V5.0

La aplicación de detección desarrollada en Android Studio y OpenCV ha evolucionado a su versión 5.0, operando como el verdadero muro de pits (*pit wall*) de nuestro sistema. Conservando las bases de comunicación USB, la interfaz a pantalla completa y el monitor serial integrado de la temporada 2025, la temporada 2026 exigió una reestructuración profunda en el motor de visión y telemetría para manejar escenarios de pista mucho más agresivos y dinámicos[cite: 1].

### Interfaz V5.0 y Monitor Serial Integrado
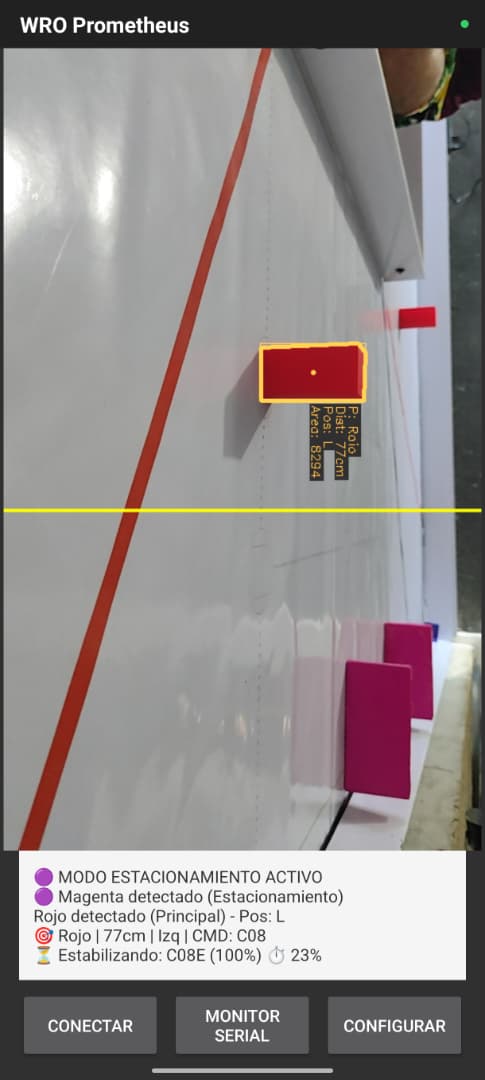
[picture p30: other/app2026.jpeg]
|  |  |
| :---: | :---: |
| *Interfaz principal con telemetría de detección dual y estabilización.* | *Monitor serial integrado operando en tiempo real.* |

A continuación, se detallan las innovaciones y sistemas implementados en el núcleo de la aplicación (`MainActivity.kt`, `ColorAnalyzer.kt` y el sistema de configuración):

### 1. Calibración en Pista y Menú Dinámico
Se eliminó la necesidad de depender de Android Studio para ajustar variables en el campo de competencia[cite: 3].
* **Calibración Automática por Muestras:** Un nuevo menú interactivo permite calibrar el matiz (Hue) y tolerancia capturando 8 muestras directas de los pilares en distintos puntos de la pista[cite: 3].
* **Ajuste Paramétrico:** Las zonas de detección de distancia, el área de referencia y los filtros se configuran directamente desde una interfaz visual sin tener que tocar código[cite: 3, 4].

### 2. Filtro Anti-Reflejos y Limpieza Geométrica
Para lidiar con los cambios de iluminación y destellos en el tapiz de la pista, se programó un blindaje en el procesamiento de imagen (`ColorAnalyzer`)[cite: 2]:
* **Filtro de Saturación Interna:** Los reflejos pierden saturación al mezclarse con el brillo de la pista[cite: 2]. El sistema analiza la saturación promedio (Canal S en HSV) *dentro* del contorno y rechaza automáticamente aquellos que presenten niveles bajos, identificándolos como destellos[cite: 2]. Estos niveles de saturación son configurables de forma independiente para el rojo y el verde desde el menú[cite: 3, 4].
* **Ecualización CLAHE:** Se aplica ecualización adaptativa de histograma al canal de brillo para normalizar la iluminación del entorno sin perder detalles críticos[cite: 2].
* **Rechazo de Formas Orgánicas:** Mediante detección de picos y conteo de defectos de convexidad, el sistema ignora geometrías con ángulos muy agudos (< 45°) o formas complejas que no correspondan a la silueta regular de un pilar o delimitador[cite: 2].

### 3. Modo Estacionamiento Dinámico (Zona Magenta)
El color magenta activa un comportamiento estratégico mediante un umbral de área específico (8000 px), asegurando que el modo despierte únicamente al entrar a ese tramo de la pista y no desde lejos[cite: 2].
* Su función no es simplemente frenar al final del circuito, sino **modificar la trayectoria de evasión**[cite: 1, 2]. 
* Al reconocer la zona de estacionamiento, el `CommandManager` ajusta la ruta para que el vehículo navegue alejado de esa área (forzando un lado específico si es necesario), evitando llevarse por delante la placa delimitadora magenta durante el trayecto[cite: 1, 2].

### 4. Filtro Temporal de Estabilización (Anti-Ruido)
Para erradicar comandos fantasma o falsos positivos, la telemetría incluye un filtro temporal estricto[cite: 1].
* **Ventana de Votación:** El sistema almacena las detecciones en una ventana deslizante de los últimos 8 fotogramas[cite: 1].
* Para que un comando tome el control del vehículo, debe dominar al menos el **70% de esa ventana** y mantenerse estable durante un umbral de **2000 milisegundos**[cite: 1].

### 5. Consolidación de Telemetría Dual y Arquitectura por Casos
Construyendo sobre la capacidad de detección dual introducida a finales de 2025, el sistema ahora engrana esta telemetría con un motor de decisiones robustecido[cite: 1]:
* El sistema continúa extrayendo el área, distancia y orientación de un objeto primario y secundario en simultáneo[cite: 1].
* Toda la lógica de decisión se extrajo del hilo principal y se encapsuló en un `CommandManager` independiente, el cual analiza esta telemetría dual bajo una arquitectura de casos predefinidos para emitir el comando exacto de evasión combinada[cite: 1].
* Para soportar la alta carga de datos con la placa ESP32, se optimizó la comunicación USB con algoritmos que interceptan y destruyen la basura binaria y los mensajes de arranque (*boot logs*) nativos del ESP32, garantizando lecturas limpias desde el primer milisegundo[cite: 1].

> [!TIP]
> **Ergonomía en Pruebas (Legado Mejorado)**
>
> Diseñada para el estrés de la competencia, la interfaz mantiene su operabilidad a pantalla completa, despierta el teléfono automáticamente al conectar el cable USB, es capaz de emitir señales acústicas únicas para cada comando enviado de forma exitosa, permitiendo al equipo monitorear el desempeño sin despegar los ojos del vehículo[cite: 1].

## Prueba de vueltas a la pista 

Haz clic en la imagen para ver el vídeo:

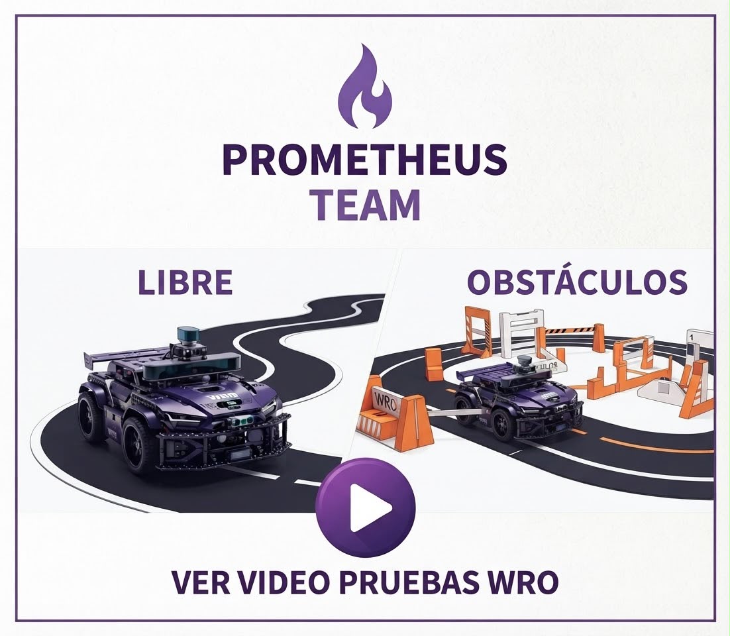
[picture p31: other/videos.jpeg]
Mira el video del proyecto (https://youtube.com/shorts/Ml_8qpX_Ozo)


## Prueba de Evasión de obstáculos 

Haz clic en la imagen para ver el vídeo:

Mira el video del proyecto (https://youtu.be/qwc4M6uargw?si=8OC0NmMWCrHWz1Wq)

# Prometheus Team - Temporada 2025

Somos un equipo venezolano que representa con orgullo a la **Universidad Politécnica Territorial José Félix Ribas (UPTJFR)**. Nuestro compromiso es la innovación y el aprendizaje continuo en el campo de la robótica autónoma.

---

##  Índice

* [Contenido del Repositorio](#contenido-del-repositorio)
* [Introducción al Proyecto](#introducción-al-proyecto)
* [Fotos de Equipo](#fotos-de-equipo)
* [Fotos del Vehículo](#fotos-del-vehiculo)
* [Diseño de Hardware](#diseño-de-hardware)
   * [Componentes de Detección](#componentes-de-detección)
   * [Componentes de Procesamiento de Información](#componentes-de-procesamiento-de-información)
   * [Componentes de Alimentación](#componentes-de-alimentación)
* [Desarrollo de la Aplicación para la Detección de Objetos](#Desarrollo-de-la-Aplicación-para-la-Detección-de-Objetos)
* [Cálculo de Torque y Velocidad](#cálculo-de-torque-y-velocidad)
* [Sistema de Alimentación](#sistema-de-alimentación)
   * [Cálculo del Consumo Energético Total](#cálculo-del-consumo-energético-total)
   * [Autonomía Estimada](#autonomía-estimada)
* [Sistema de Detección de Objetos](#sistema-de-detección-de-objetos)
* [Paso a Paso de la Construcción](#paso-a-paso-de-la-construcción)
   * [Etapa de Diseño y Ensamblaje del Vehículo](#etapa-de-diseño-y-ensamblaje-del-vehículo)
   * [Montaje del Vehículo](#montaje-del-vehículo)
   * [Diseño de Base 3D](#diseño-de-base-3d)
   * [Cambio de Base](#cambio-de-base)
   * [Problemas Encontrados](#problemas-encontrados)
* [Pruebas Realizadas](#pruebas-realizadas)
   * [Prueba del Sensor de Color](#prueba-del-sensor-de-color)
   * [Fabricación de Pista a Escala](#fabricacion-de-pista-a-escala)
   * [Desarrollo de la Lógica de Vueltas a la Pista](#desarrollo-de-la-logica-de-vueltas-a-la-pista)
   * [Desarrollo de la Lógica de Evasión de Objetos](#desarrollo-de-la-logica-de-evasion-de-objetos)
   * [Desarrollo de Códigos Combinados](#desarrollo-de-códigos-combinados)
   * [Video Resumen de las Pruebas](#video-resumen-de-las-pruebas-de-vuelta-a-la-pista-y-esquive-de-objetos)
   * [Prueba de Vueltas a la Pista](#prueba-de-vueltas-a-la-pista)
   * [Prueba de Evasión de Obstáculos](#prueba-de-evacion-de-obstaculos)
---

##  Contenido del Repositorio

Este repositorio contiene los siguientes directorios para organizar nuestro proyecto:

* `t-photos`: Incluye 2 fotos del equipo (una oficial y una divertida con todos los miembros).
* `v-photos`: Contiene 6 fotos del vehículo (desde todos los ángulos, superior e inferior).
* `video`: Archivo `video.md` con el enlace a un video de demostración de conducción.
* `schemes`: Diagramas esquemáticos (JPEG, PNG o PDF) de los componentes electromecánicos, ilustrando la conexión de elementos electrónicos y motores.
* `src`: Código del software de control para todos los componentes programados para la competición.
* `models`: Archivos para modelos usados por impresoras 3D, cortadoras láser y máquinas CNC para producir elementos del vehículo.
* `other`: Archivos adicionales para entender cómo preparar el vehículo para la competición (documentación de conexión SBC/SBM, carga de archivos, especificaciones de hardware, etc.).

---

##  Introducción al Proyecto

Para esta competición, hemos desarrollado un diseño de vehículo **cómodo, fácil de modificar y sencillo**, donde todos los elementos interactúan a la perfección. Nos enorgullece presentar nuestro primer prototipo de vehículo autónomo con reconocimiento de objetos y colores.

El diseño y la construcción de nuestro vehículo son íntegramente propios. Su **estructura de dos niveles** permite que todos los componentes encajen armoniosamente. Incorpora **vigas de soporte extraíbles** para facilitar el desmontaje, un **sistema de transmisión** tipo LEGO que transfiere la potencia del motor a las ruedas traseras, y un **sistema de dirección** también con piezas LEGO, controlado por un servomotor para mayor precisión en los giros.

Este proyecto ha sido el resultado del esfuerzo y la dedicación de todo nuestro equipo. Cada cable, cada sensor, y cada línea de código es un testimonio de nuestro **esfuerzo técnico y financiero**. No solo construimos un vehículo; demostramos que con pasión y ganas de aprender, se pueden superar los límites.

---
##  Fotos de equipo
| Foto Oficial  | Foto Equipo | 
| :----: | :--- |

---
##  Fotos del vehiculo 
| Arriba del vehiculo  |  Debajo de vehiculo  |  Lateral derecho |
| :----: | :--- | :--- |
| lateral izquierdo  |  frente  |  detras |

---

##  Diseño de Hardware

Control Principal

| Imagen | Nombre de Componente | Descripción |
| :----: | :--- | :--- |
| Base del Primer Piso | **Base del Vehículo** | Con medidas de 11.5 cm x 2.5 cm, imita un coche de Fórmula 1, optimizando la distribución de espacio y la movilidad. La parte frontal permite alojar tres sensores (1 ultrasónico central y 2 infrarrojos diagonales). Aunque el cartón inicial presentó debilidades en la dirección, el uso de acrílico o un material más rígido es la solución ideal. |
| Transmisión | **Sistema de Transmisión de Legos** | Distribuye la potencia del motor entre ambas ruedas traseras, permitiendo el giro continuo del motor incluso si una rueda se bloquea y evitando daños. Elegido por su facilidad de uso y tamaño adecuado, permite también la reversa. |
| Motor | **25GA370 Motor DC con Encoder** | Motor común en estos vehículos por su potencia y velocidad. El codificador integrado mide velocidad y dirección (aún no utilizado). **Especificaciones**: Potencia nominal: 4 W, Tensión nominal: 6V, Velocidad nominal: 220 RPM, Peso: 400g, Caja reductora: 21.3:1, Torque nominal: 0.35 kg·cm. |
| Dirección | **Sistema de Dirección** | Construido con piezas LEGO, su tamaño es ideal y permite adaptar un servomotor de 180 grados para controlar el movimiento. El servomotor se centra a 90 grados, gira a la izquierda a 180 grados y a la derecha a 0 grados. |
| Separadores | **Separadores de Acrílico** | Facilitan un montaje cómodo y modular. Girar los pilares permite desatornillar y desmontar el vehículo rápidamente. |

### Componentes de Detección

| Imagen | Nombre de Componente | Descripción |
| :----: | :--- | :--- |
| Sensor Ultrasónico | **Sensor Ultrasónico HC-SR04** | Mide la distancia a obstáculos mediante ondas ultrasónicas. Lo utilizamos en la parte frontral, lateral izquierda, lateral derecha y en la parte trasera del vehiculo para detectar proximidad. |
| Sensor Infrarrojo | **Sharp GP2Y0A21YK0F Sensor Infrarrojo** | Garantiza una detección de objetos rápida y precisa. Se ubican en las diagonales delanteras del vehículo. |
| Sensor Color | **TCS34725 Sensor de Colores** | Permite una detección precisa del color a corta distancia, ubicado en la parte inferior para identificar los colores de las franjas de la pista. Alta sensibilidad y amplio rango dinámico (3.800.000:1), funcionando incluso tras cristales oscuros. |
| Giroscopio | **MPU6050 Sensor Giroscopio y Acelerómetro** | Unidad de medición inercial (IMU) de 6 grados de libertad (DoF) que combina un acelerómetro y un giroscopio de 3 ejes. Ampliamente utilizado en navegación, radiogoniometría y estabilización. |
| Magnetometro | **Magnetómetro GY-273 HMC5883L** | Funciona como una brújula digital, midiendo la intensidad y la dirección del campo magnético de la Tierra en sus tres ejes (X, Y, Z). Al detectar este campo, puede determinar su orientación con respecto al norte magnético. |
| Cámara Celular | **Cámara del Teléfono Celular** | Utilizando una app desarrollada en android studio usando las librerias de OpenCV, el celular en general se usa como procesador de imagenes y la cámara del celular se usa como sensor para identificar el color y los objetos. |

### Componentes de Procesamiento de Información

| Imagen | Nombre de Componente | Descripción |
| :----: | :--- | :--- |
| ESP32 | **Microcontrolador ESP32** | Actúa como el cerebro del vehículo, conectando y controlando todos los sensores y motores. |

### Componentes de Alimentación

| Imagen | Nombre de Componente | Descripción |
| :----: | :--- | :--- |
| Batería | **Batería LiPo 2200mAh 7.4V** | Fuente de alimentación recargable que alimenta todo el sistema, proporcionando movilidad y autonomía. Seleccionada por su capacidad para suministrar suficiente energía a los motores y componentes internos. |
| Regulador | **LM2596 Regulador de Voltaje** | Reduce el voltaje de manera eficiente. Voltaje de entrada: 4.5 V a 40 V CC. Voltaje de salida: 1.23 V a 37 V CC. Corriente de salida: Máx. 3 A, se recomiendan 2.5 A. |

---

# Desarrollo de la Aplicación para la Detección de Objetos

Para la detección de obstáculos, hemos desarrollado una aplicación móvil usando **Android Studio** e implementando la biblioteca **OpenCV**, la app es el cerebro de nuestro vehículo autónomo en cuanto a resolución de obstáculos se refiere. Permite que nuestro vehiculo identifique y reaccione de forma inteligente a los obstáculos en su entorno. El sistema procesa imágenes en tiempo real capturadas por la cámara del teléfono y, mediante una comunicación serial confiable, envía comandos específicos a una placa **Arduino/ESP32** para controlar el comportamiento del vehiculo en el campo de competición.

| Logo de OpenCV | Logo de Android Studio |
| :---: | :---: |

---
A continuación, detallaremos algunas de las versiones más importantes de nuestra aplicación, mostrando la evolución del sistema de detección a lo largo del desarrollo y cómo cada etapa nos ayudó a superar los desafíos del proyecto.

## Versión 1: Detección Básica de Colores

Esta es la primera versión del sistema, enfocada en la detección simple de colores. Su objetivo principal era identificar objetos de color **rojo** y **verde** para enviar un comando básico (`R` para rojo, `G` para verde) a través de una conexión USB a la placa Arduino.

El mayor reto en esta etapa fue lograr la comunicación efectiva entre un dispositivo móvil Android y un microcontrolador como el Arduino. Después de numerosos intentos y ajustes, se consiguió establecer una conexión estable y que el Arduino recibiera comandos, al menos de forma básica. Además, fue un desafío significativo lograr aprovechar al máximo la librería **OpenCV** en un entorno móvil, dadas las complejidades de su instalación y configuración en dispositivos Android, pero este obstáculo también fue superado con éxito.

**Imágenes de la Versión 1:**

|  |  |
| :---: | :---: |

---

---

---

## Versión 2: Mejora en Detección y Comunicación

Se introdujeron mejoras significativas para hacer el sistema más robusto y preciso. Uno de los principales retos fue **optimizar la aplicación** para que los comandos se enviaran y fueran recibidos por el Arduino lo más rápido posible, al mismo tiempo que se lograba reconocer con precisión la **distancia** y **orientación** del objeto.

Con respecto a la orientación, una complicación particular surgió debido a la **posición horizontal de la cámara** en el teléfono. Al dividir la pantalla en tres sectores para determinar la ubicación del objeto, la perspectiva de la cámara causaba distorsiones, haciendo que un objeto pareciera estar más hacia un lado del vehículo de lo que realmente estaba.

### Cálculo de Distancia por Área

Para estimar la distancia al objeto, se implementó un método basado en la relación inversa entre la distancia y el área aparente del objeto en la imagen. El principio es simple: **cuanto más lejos está un objeto, más pequeño se ve**. Este enfoque requiere una calibración inicial para funcionar.

La fórmula utilizada es la siguiente:

$$ \text{Distancia} = \text{DistanciaConocida} \times \sqrt{\frac{\text{AreaConocida}}{\text{AreaMedida}}} $$

Donde:
* **DistanciaConocida**: Es una distancia fija y conocida a la que se calibra el sistema (por ejemplo, 30 cm).
* **AreaConocida**: Es el área en píxeles que ocupa el objeto en la imagen cuando se encuentra a la `DistanciaConocida`. Este valor se guarda una vez durante la calibración.
* **AreaMedida**: Es el área actual en píxeles que el objeto ocupa en la imagen durante la detección en tiempo real.

Este método permite que, tras una única calibración, el sistema pueda estimar la distancia de forma continua simplemente midiendo el tamaño del objeto detectado.

A pesar de los desafíos, se implementaron las siguientes mejoras:

* **Filtrado de Formas:** La aplicación ahora filtra las imágenes para reconocer específicamente **formas rectangulares**, lo que reduce los falsos positivos y mejora la precisión.
* **Comunicación Detallada:** Se mejoró la comunicación con Arduino para transmitir información más completa. Ahora se envían la **distancia** y la **orientación** del objeto, además de su color.
* **Mejoras en la UI:** Se optimizó el comportamiento general de la aplicación y se realizaron cambios sutiles en la interfaz de usuario para una mejor experiencia.

**Imágenes de la Versión 2:**

|  |  |
| :---: | :---: |

---

## Versión 3: Sistema de Detección Avanzado y Profesional

Esta versión representa una **reestructuración completa** y un salto cualitativo en el sistema, adaptándose a las nuevas necesidades y a un cambio en la plataforma del vehículo. Tras evaluar los resultados obtenidos en los regionales del país, se hizo evidente la necesidad de un sistema más avanzado y robusto capaz de mejorar significativamente el **esquive de obstáculos**.

Para ello, se realizó un cambio en el vehículo para usar un ESP32 como microcontrolador principal, lo que requirió que la aplicación también se adaptara a esta nueva plataforma. La estrategia clave fue desarrollar un sistema capaz de reconocer dos objetos a la vez y establecer rutas de forma anticipada, en lugar de esquivar los obstáculos uno a uno en tiempo real. Esto llevó la automatización de nuestro vehículo a otro nivel.

Sin embargo, la implementación de la detección dual presentó varios desafíos. El más evidente fue que requirió rehacer gran parte del código de envío de comandos. Para resolverlo, decidimos crear un archivo independiente, el CommandManager, que se encarga exclusivamente de la lógica de comandos y de gestionar la información de cada combinación de obstáculos o "caso".

Además, surgió la necesidad de elevar el teléfono para que la cámara pudiera observar ambos objetos cuando uno estuviera detrás del otro. Esto nos obligó a realizar una modificación en la base del vehículo, un cambio que se detalla más a fondo en la sección correspondiente de nuestro repositorio. Finalmente, una vez resueltos estos retos, se llevaron a cabo una gran cantidad de pruebas para asegurar que el sistema fuera robusto y pudiera enfrentar de manera fiable las distintas combinaciones de obstáculos en la competición.
Se lograron importantes avances:

* **Solución al Problema de Orientación:** Se corrigió el problema anterior con la división de la pantalla y la orientación. En esta versión, no usamos una división en tres sectores; simplemente dividimos la pantalla en **izquierda y derecha** para identificar la posición lateral de los objetos.
* **Cálculo de Distancia Avanzado:** El cálculo de distancia se encarga de identificar la posición longitudinal de los objetos (adelante, medio o atrás). Mediante algunos "trucos" y algoritmos optimizados, logramos filtrar y reconocer de manera efectiva **cada caso de colisión o esquive**.
* **Interfaz Profesional:** La interfaz de usuario fue completamente **rediseñada** para ser más intuitiva, profesional y pulida, ofreciendo una experiencia de usuario superior.
* **Monitor Serial Integrado:** La incorporación de un **monitor serial** para recibir información directamente del microcontrolador ha sido fundamental para el **debug** y las pruebas en tiempo real, agilizando el desarrollo.
* **Diseño Único:** La nueva interfaz no solo es 100% más práctica, sino que también cuenta con un diseño único que representa la identidad de nuestro equipo: **Prometheus Team**.

**Imágenes de la Versión 3:**
|  |  |
| :---: | :---: |

---

## 📱 Telemetría y Visión Artificial: Aplicación Prometheus V5.0

La aplicación de detección desarrollada en Android Studio y OpenCV ha evolucionado a su versión 5.0, operando como el verdadero muro de pits (*pit wall*) de nuestro sistema. Conservando las bases de comunicación USB, la interfaz a pantalla completa y el monitor serial integrado de la temporada 2025, la temporada 2026 exigió una reestructuración profunda en el motor de visión y telemetría para manejar escenarios de pista mucho más agresivos y dinámicos.

### Interfaz V5.0 y Monitor Serial Integrado
|  |  |
| :---: | :---: |
| *Interfaz principal con telemetría de detección dual y estabilización.* | *Monitor serial integrado operando en tiempo real.* |

A continuación, se detallan las innovaciones y sistemas implementados en el núcleo de la aplicación (`MainActivity.kt`, `ColorAnalyzer.kt` y el sistema de configuración):

### 1. Calibración en Pista y Menú Dinámico
Se eliminó la necesidad de depender de Android Studio para ajustar variables en el campo de competencia.
* **Calibración Automática por Muestras:** Un nuevo menú interactivo permite calibrar el matiz (Hue) y tolerancia capturando 8 muestras directas de los pilares en distintos puntos de la pista.
* **Ajuste Paramétrico:** Las zonas de detección de distancia, el área de referencia y los filtros se configuran directamente desde una interfaz visual sin tener que tocar código.

### 2. Filtro Anti-Reflejos y Limpieza Geométrica
Para lidiar con los cambios de iluminación y destellos en el tapiz de la pista, se programó un blindaje en el procesamiento de imagen (`ColorAnalyzer`):
* **Filtro de Saturación Interna:** Los reflejos pierden saturación al mezclarse con el brillo de la pista. El sistema analiza la saturación promedio (Canal S en HSV) *dentro* del contorno y rechaza automáticamente aquellos que presenten niveles bajos, identificándolos como destellos. Estos niveles de saturación son configurables de forma independiente para el rojo y el verde desde el menú.
* **Ecualización CLAHE:** Se aplica ecualización adaptativa de histograma al canal de brillo para normalizar la iluminación del entorno sin perder detalles críticos.
* **Rechazo de Formas Orgánicas:** Mediante detección de picos y conteo de defectos de convexidad, el sistema ignora geometrías con ángulos muy agudos (menores a 45°) o formas complejas que no correspondan a la silueta regular de un pilar o delimitador.

### 3. Modo Estacionamiento Dinámico (Zona Magenta)
El color magenta activa un comportamiento estratégico mediante un umbral de área específico (8000 px), asegurando que el modo despierte únicamente al entrar a ese tramo de la pista y no desde lejos.
* Su función no es simplemente frenar al final del circuito, sino **modificar la trayectoria de evasión**. 
* Al reconocer la zona de estacionamiento, el `CommandManager` ajusta la ruta para que el vehículo navegue alejado de esa área (forzando un lado específico si es necesario), evitando llevarse por delante la placa delimitadora magenta durante el trayecto.

### 4. Filtro Temporal de Estabilización (Anti-Ruido)
Para erradicar comandos fantasma o falsos positivos, la telemetría incluye un filtro temporal estricto.
* **Ventana de Votación:** El sistema almacena las detecciones en una ventana deslizante de los últimos 8 fotogramas.
* Para que un comando tome el control del vehículo, debe dominar al menos el **70% de esa ventana** y mantenerse estable durante un umbral de **2000 milisegundos**.

### 5. Consolidación de Telemetría Dual y Arquitectura por Casos
Construyendo sobre la capacidad de detección dual introducida a finales de 2025, el sistema ahora engrana esta telemetría con un motor de decisiones robustecido:
* El sistema continúa extrayendo el área, distancia y orientación de un objeto primario y secundario en simultáneo.
* Toda la lógica de decisión se extrajo del hilo principal y se encapsuló en un `CommandManager` independiente, el cual analiza esta telemetría dual bajo una arquitectura de casos predefinidos para emitir el comando exacto de evasión combinada.
* Para soportar la alta carga de datos con la placa ESP32, se optimizó la comunicación USB con algoritmos que interceptan y destruyen la basura binaria y los mensajes de arranque (*boot logs*) nativos del ESP32, garantizando lecturas limpias desde el primer milisegundo.

> [!TIP]
> **Ergonomía en Pruebas (Legado Mejorado)**
>
> Diseñada para el estrés de la competencia, la interfaz mantiene su operabilidad a pantalla completa, despierta el teléfono automáticamente al conectar el cable USB, es capaz de emitir señales acústicas únicas para cada comando enviado de forma exitosa, permitiendo al equipo monitorear el desempeño sin despegar los ojos del vehículo.

----

### Video del Funcionamiento en Vivo de la Aplicación

Mira el video del funcionamiento en vivo de la aplicación (https://youtu.be/TpLVCiggEwY)

---

##  Cálculo de Torque y Velocidad

### Cálculo de Torque Necesario para Mover el Vehículo:

El torque necesario ($T_{\text{necesario}}$) se calcula mediante la fórmula:
$T_{\text{necesario}} = m \cdot g \cdot r$

Donde:
* $m$ = masa del vehículo (0.943 kg)
* $g$ = gravedad (9.81 $m/s^2$)
* $r$ = radio de las ruedas (0.04 m)

$T_{\text{necesario}} = 0.943 \cdot 9.81 \cdot 0.04 = 0.370 \text{ N} \cdot \text{m}$

### Cálculo de Torque a la Salida (después de la reducción) según el motor DC 25GA370:

$T_{\text{salida}} = T_{\text{motor}} \cdot \text{Reducción}$
$T_{\text{salida}} = 0.0343 \cdot 21.3 = 0.7306 \text{ N} \cdot \text{m}$

### Cálculo de la Velocidad Lineal del Vehículo:

Convertimos la velocidad del motor a radianes por segundo ($\omega$):
$\omega = \frac{220 \cdot 2\pi}{60} = 23.04 \text{ rad/s}$

Velocidad lineal del vehículo ($v$):
$v = \omega \cdot r = 23.04 \cdot 0.04 \approx 0.92 \text{ m/s}$

El motor empleado tiene una velocidad sin carga de 4690 RPM y un torque nominal de 0.35 kg·cm (0.0343 N·m). Mediante una caja reductora de 21.3:1, la velocidad se reduce a 220.2 RPM en el eje de salida, lo que resulta en una velocidad lineal del vehículo de aproximadamente 0.92 m/s.

Gracias a esta reducción, el torque en las ruedas alcanza 0.7306 N·m, lo cual supera el torque mínimo necesario para mover el vehículo de 943 gramos (0.370 N·m). Por lo tanto, el sistema cumple adecuadamente los requerimientos de tracción y movilidad para condiciones normales.

---

##  Sistema de Alimentación

###  Versión 1:

Diagrama de Alimentación 1

Este diagrama representa la versión inicial del sistema de alimentación de nuestro proyecto, concebido con una configuración de componentes más simple. 

En esta iteración, el circuito se alimenta por completo a través de una **batería LiPo de 2200 mAh** (7.4V), cuya energía se distribuye a los distintos módulos después de pasar por un interruptor principal de encendido. Un **regulador de voltaje XL6009** eleva el voltaje para alimentar el puente H **L298N**, asegurando que nuestro motor DC reciba la tensión de funcionamiento adecuada. 

De forma paralela, un **módulo DSN-Mini 360** se encarga de reducir el voltaje de la batería para alimentar directamente el pin Vin de la placa **Arduino**, que a su vez controla el servomotor de dirección. Este diseño sienta las bases del sistema, aunque futuras versiones incorporarán más componentes para optimizar su rendimiento.

###  Versión 2:

Diagrama de Alimentación 2

 #### Cambios agregados a las conexiones en el sistema de alimentacion:
  1. Alimentamos ambos microcontroladores con el mismo reductor de voltaje a 7v.
  2. Agregamos un reductor de voltaje exclusivo para sensores ultrasonicos e infrarrojos y el servomotor de la direccion(que ahora se alimenta del reducctor y no del arduino).
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

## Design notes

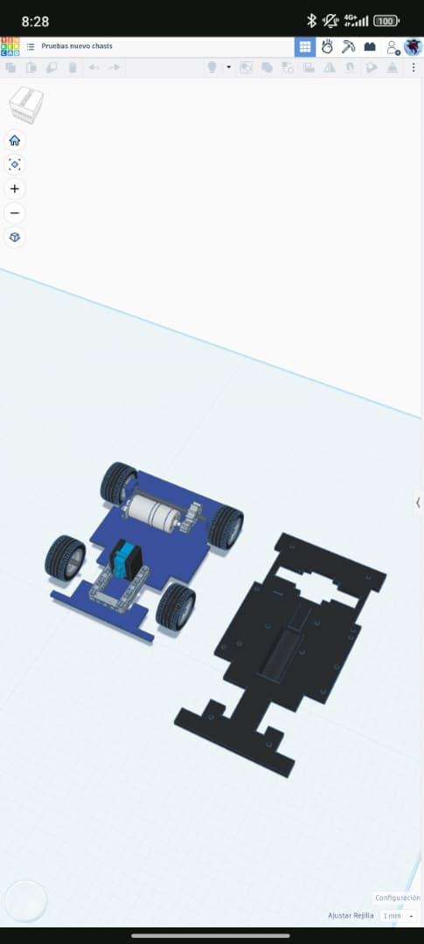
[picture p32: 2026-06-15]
other/comparacion3dBase2026.jpeg

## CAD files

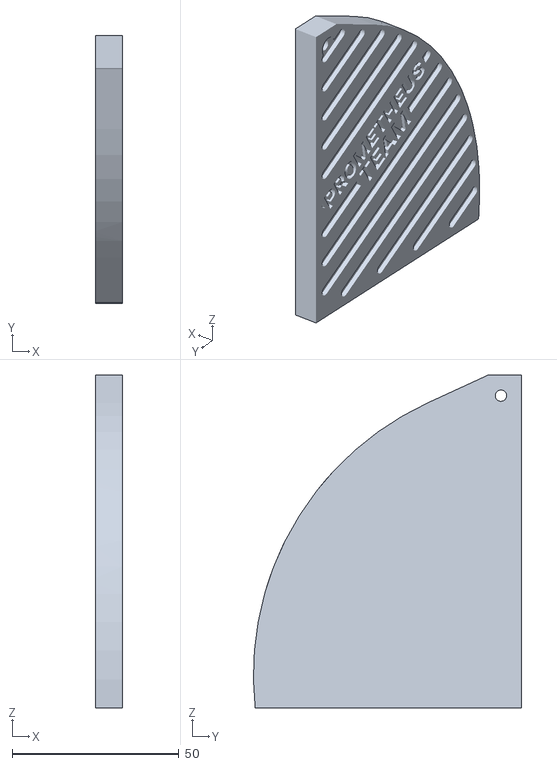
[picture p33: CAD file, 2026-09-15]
models/Torre_Derecha_2026.stl
8.00 x 80.5 x 100.0

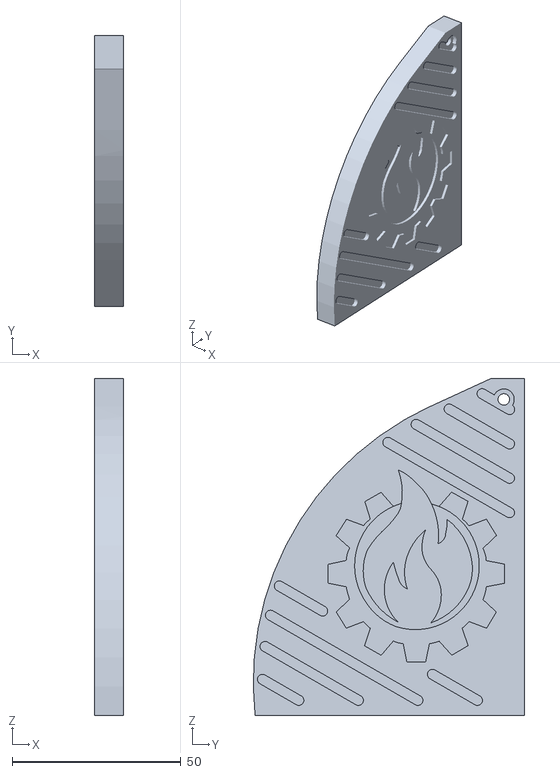
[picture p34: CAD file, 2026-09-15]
models/Torre_Izquierda_2026.stl
8.50 x 80.5 x 100.0

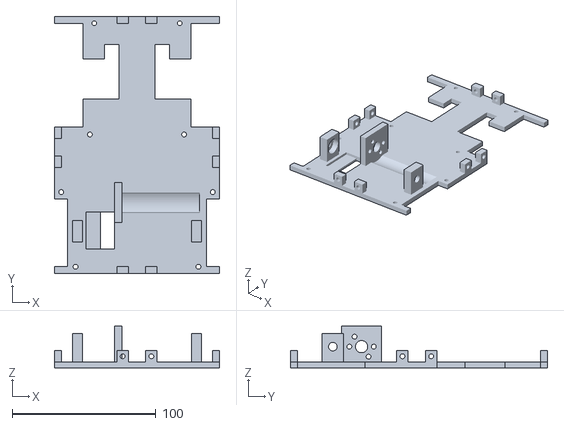
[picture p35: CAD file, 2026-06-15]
models/Primer_Piso_Vehiculo_2026.stl
115.0 x 179.0 x 29.0

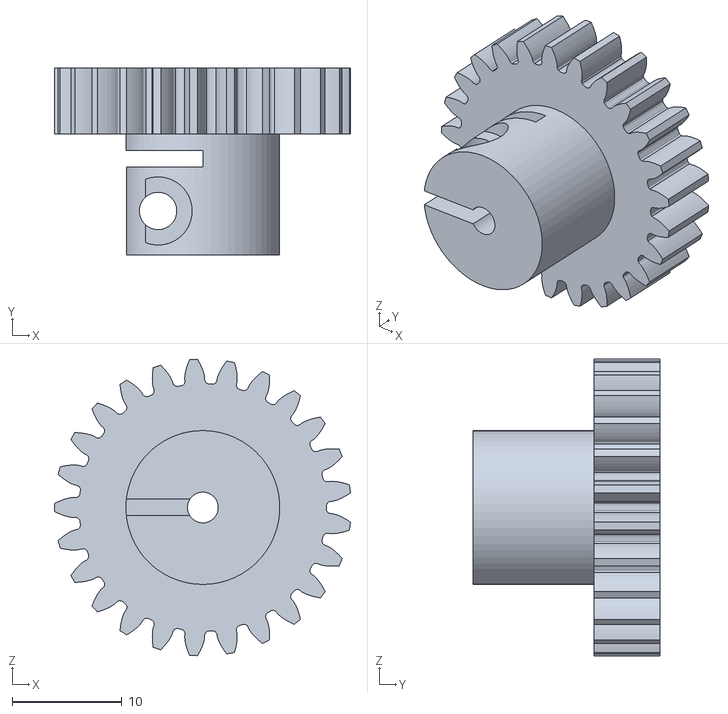
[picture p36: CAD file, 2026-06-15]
models/Engranaje_25teeth_2026.stl
26.9 x 17.0 x 27.0

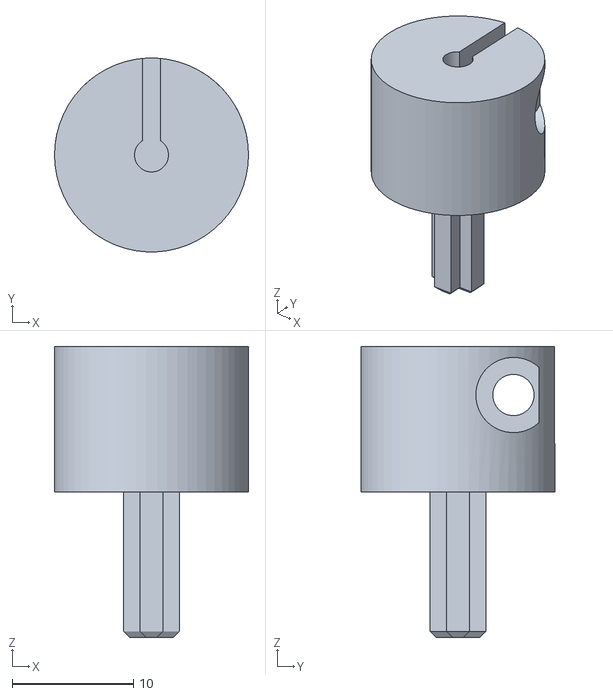
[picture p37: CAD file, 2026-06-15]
models/Adaptador_Lego_2026.stl
16.0 x 16.0 x 24.0

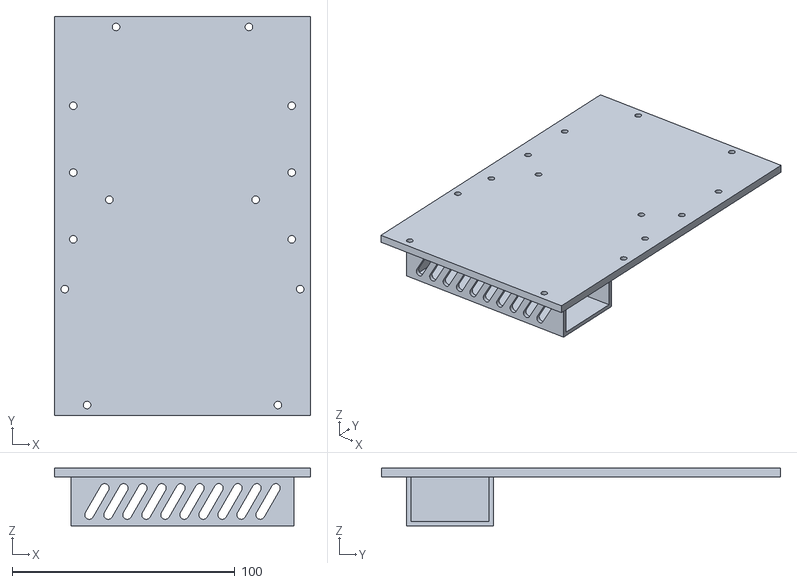
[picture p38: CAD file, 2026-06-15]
models/Segundo_piso_vehiculo_2026.stl
115.0 x 179.0 x 26.0

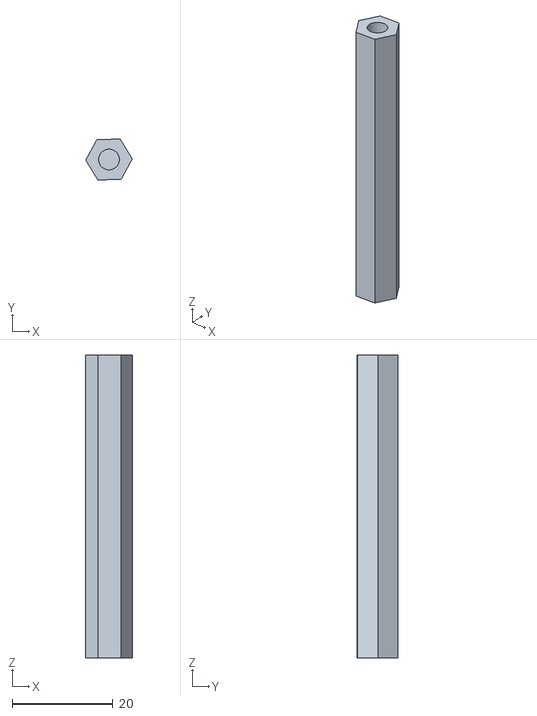
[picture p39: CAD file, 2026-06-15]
models/Separador_2026.stl
9.24 x 8.11 x 60.0

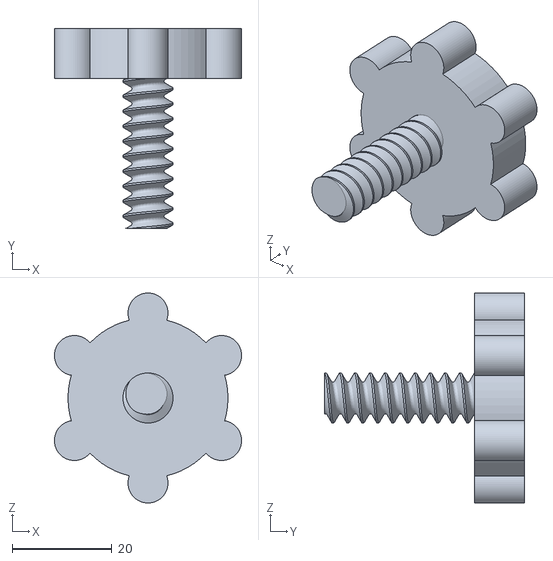
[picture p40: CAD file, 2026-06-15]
models/Tornillo_Mordaza_2026.stl
37.4 x 40.0 x 42.0

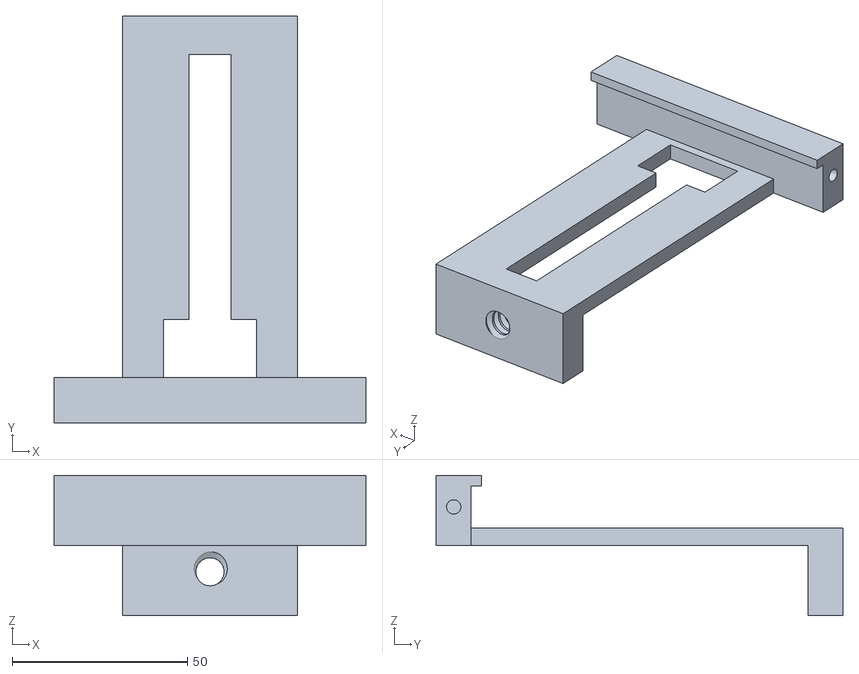
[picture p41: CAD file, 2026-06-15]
models/Base_Fija_Mordaza_2026.stl
89.0 x 116.0 x 40.0

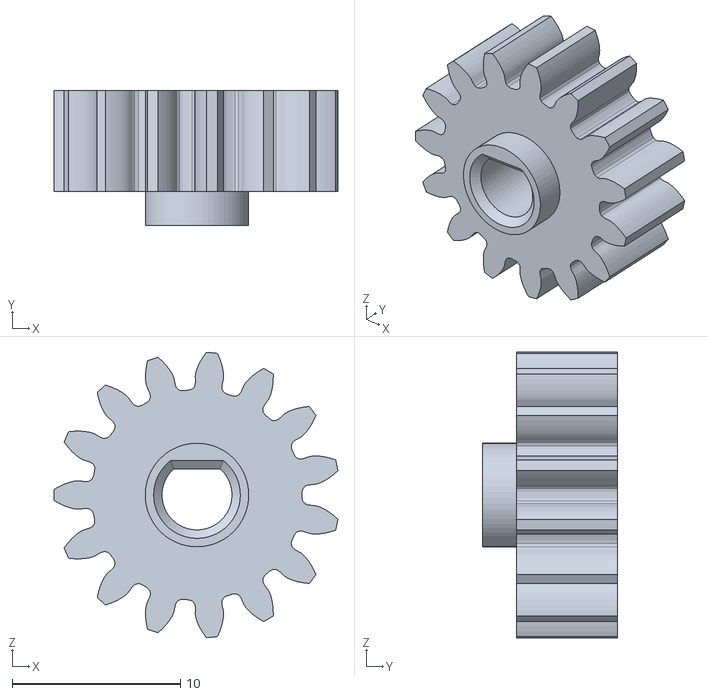
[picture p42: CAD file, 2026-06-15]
models/Engranaje_15teeth_2026.stl
16.9 x 8.00 x 17.0

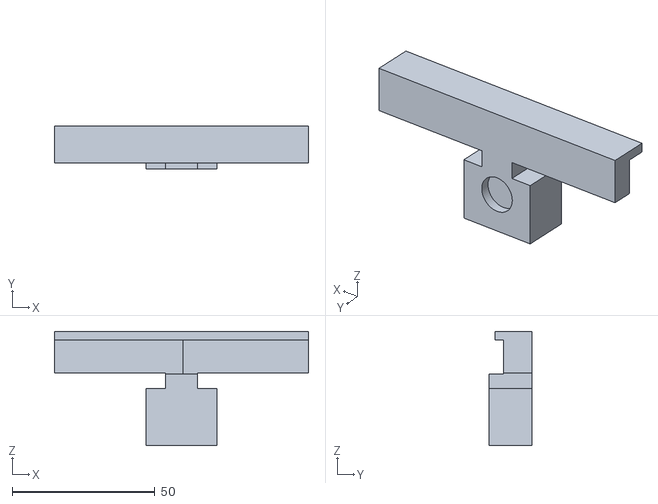
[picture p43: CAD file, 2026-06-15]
models/Mordaza_Movil_2026.stl
89.0 x 15.0 x 40.0

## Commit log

2026-06-15 Update README with version 4 schematics and changes
    Added detailed descriptions of power and sensor schematics for version 4, including improvements and component changes.
2026-06-15 Add track lap test section to README
    Added a section for track lap test with a video link.
2026-06-15 stls modelos 3d
    [Adaptador_Lego_2026.stl, Base_Fija_Mordaza_2026.stl, Engranaje_15teeth_2026.stl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]
2026-06-15 Refactor README to remove duplicate chassis assembly section
    Removed duplicate section on chassis assembly and optimization details, while retaining the updated section for the chassis assembly.
2026-06-15 Revise README for software continuity and BNO055 integration
    Updated the README to reflect changes in software development continuity and the integration of the BNO055 sensor, highlighting improvements in vehicle control and navigation algorithms.
2026-06-16 Expand README with energy management and autonomy details
    Added section on energy management and system autonomy, including power consumption calculations and battery selection justification.
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2026-10-29 README: corrige inconsistencias y condensa la temporada 2025
2026-11-03 Agrega la dirección Ackermann: sección 9.4 del README y documento técnico en docs/
    - docs/direccion-ackermann.md: cálculos, verificación en CAD, mediciones,
    comparación con la dirección Lego y decisiones de diseño.
    - docs/Direccion_Ackermann_Calculos_y_Justificacion.docx: documento original.
    - README: nueva sección 9.4 (renumera 9.5 a 9.8), guía de ensamble paso 4,
    servo, dimensiones (ancho con ruedas y radio de giro), PETG-CF,
    tabla 2025 vs 2026 y estructura del repositorio.
2026-11-03 README: 2025 en inglés y condensado, numeración completa e índice con anclas nativas
    - Sección 18 (temporada 2025) reducida y traducida al inglés.
    - Todos los títulos numerados (pasos de la guía como 13.x, interfaz de la app como 15.1).
    - Títulos sin emojis y enlaces internos con las anclas que genera GitHub,
    en lugar de etiquetas <a id> manuales.
    - Índice regenerado a partir de los títulos.
2026-11-03 Reorganiza el repositorio al estilo de documentación por secciones
    - README: encabezado con insignias y cifras clave, estructura del repo,
    desafíos y criterios de evaluación 2026, resumen del vehículo y
    arquitectura del sistema; emojis en los títulos; índice regenerado.
    - Dirección Ackermann ampliada en el README (fórmulas, elección de K,
    servo CAD vs real, verificación CAD, mediciones y decisiones).
    - Diagramas de flujo nuevos: arquitectura, arranque, detección de líneas,
    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
2026-11-03 Quita las mejoras futuras y el archivo de video duplicado
    - README: se eliminan las secciones de mejoras futuras (9.5, 10.9 y 15.7);
    se agregarán cuando el equipo defina las próximas modificaciones.
    - video/video2026: duplicaba el contenido de video/video.md.
2026-11-03 Quita la sección de uso de GitHub y el video del año pasado en pruebas
    - README: se elimina la sección 18 (uso de GitHub y replicación); el
    archivo de 2025 pasa a ser la 18.
    - Sección 17: se quita el video de vueltas a la pista, que era del año
    pasado; queda el de evasión de obstáculos 2026.
    - video/: el mismo video sale de los listados de 2026.
2026-11-03 Pruebas 2026: vuelve el video de vueltas y se quita la foto de la pista
    La foto de la pista de pruebas era del año pasado; el video de vueltas a
    la pista sí es de 2026 y vuelve a la sección 17 y a video/.
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2026-11-05 Ackermann completa en el README, sección de GitHub e IA y criterios oficiales
    - 10.4: todo el documento de la dirección Ackermann pasa al README
    (datos de partida, relación 1:1 frente a 2025, fórmulas, elección de K,
    servo y biela, disposición vertical, verificación CAD, resultados,
    ajustes, comparación y decisiones), con 4 imágenes del CAD.
    - Se elimina docs/ (el documento y el .docx) y sus referencias.
    - 18: vuelve Uso de GitHub y replicación, ahora con la declaración de uso
    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
2026-11-05 Corrige descripciones de la dirección y actualiza schemes/README
    - 10.4: el violeta es el soporte del servo; la biela une el brazo del servo
    con la barra en un agujero a 14 mm del centro (por eso se ve asimétrica).
    - Guía de ensamble, paso 4: la biela va al tercer agujero de la barra,
    no a uno central.
    - Componentes, 4.1, 7.2 y 11: se alinean con el esquema de alimentación
    nuevo (tres Mini 360, diodo 1N4007, servo a 6 V).
    - schemes/README.md: imágenes FINALS y el mismo texto de las secciones 7 y 8.
2026-11-06 Agrega próximas mejoras de hardware y quita la guía de replicación
    - Componentes (5 y 6): VL53L1X, VL53L5CX, VL53L0X diagonales, EMAX
    ES08MD II y varilla de acero de 4 mm, marcados como próximo cambio.
    - Nueva sección 18. Próximas mejoras: resumen de cambios, nueva
    distribución de sensores, mejoras esperadas y ajustes necesarios.
    - Se quita Cómo replicar el proyecto; GitHub e IA pasa a la 19 y el
    archivo 2025 a la 20; índice y enlaces actualizados.
    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
2026-11-06 Recalcula la autonomía con el regulador nuevo y usa el EMAX ES08MD
    - 9.1 a 9.4: tres Mini 360 (control a 6 V con diodo 1N4007, servo a 6 V
    y línea general de 5 V); autonomía real de ~1 h 54 min.
    - Encabezado: autonomía actualizada.
    - Servo próximo: EMAX ES08MD (digital, 2,0 kgf·cm a 6 V) en componentes,
    10.4.1 y sección 18.
2026-11-06 Quita la varilla de acero de las próximas mejoras y agrega la foto del EMAX ES08MD
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
